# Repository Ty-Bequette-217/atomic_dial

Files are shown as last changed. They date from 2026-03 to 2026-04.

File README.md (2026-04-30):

# 🚧 GitHub still in progress 🚧
# The Atomic Dial
### by Yonathan Gur, Ryan Gelston, Ty Bequette, and Cody Fuh

---

## Overview
The Atomic Dial is an open-source, haptic-enabled smart knob powered by the RP2350B architecture. It provides software-defined mechanical feedback—such as detents, virtual end-stops, and magnetic resistance—using a brushless DC motor. An adaptation of the [SmartKnob](https://github.com/scottbez1/smartknob) project by Scott Bezek, this project adapts the original device to work smoothly with the RP2350B microcontroller. The board was designed to include header pins to plug in the [Proton development board](https://ece362-purdue.github.io/proton-labs/) designed by staff for ECE 36200: Microprocessor Systems and Interfacing at Purdue University.

## Board Design & Hardware Integration
Transitioning from the original ESP32-PICO architecture to the RP2350B required a redesign of the Base PCB and hardware routing to accommodate the Proton development board. We designed a custom baseplate PCB that features female headers specifically spaced to receive the Proton board. These header pins allow anyone with a Proton board to easily recreate this project and use it with their own boards. A bulk of the work done here was carefully rerouting the signals for each of the peripherals to match the correct function needed for compatibility with the proton board (see [electronics/ProjectPinAssignments.xlsx](https://github.com/Ty-Bequette-217/atomic_dial/blob/main/electronics/ProjectPinAssignments.xlsx)).

## Firmware Architecture
To make the RP2350B drive a display, read sensors, and commutate a motor simultaneously without stuttering, the firmware is divided into distinct, non-blocking layers built on the Raspberry Pi Pico C/C++ SDK.

### AS5600 Magnetic Encoder
The AS5600 serves as the primary feedback loop for our haptic system. Mounted directly below the diametric magnet on the motor shaft, it continuously reads the absolute angular position of the knob. By feeding this high-resolution rotational data back into the RP2350B, the firmware can calculate exact phase angles and trigger localized spikes in motor torque, allowing the user to feel physical "clicks" entirely generated by software.

### GC9A01 Round LCD
The primary user interface is driven by a 1.28-inch GC9A01 circular LCD, which receives data over the RP2350B's hardware SPI bus to maintain a high framerate.

#### Initialization for GC9A01
Bringing up the GC9A01 requires a precise sequence of initialization commands sent over SPI. The firmware configures the display out of sleep mode, sets the pixel format to 16-bit color (RGB565), defines the memory access control for correct screen orientation, and establishes the circular column and row address windows. A hardware reset line is toggled on boot to ensure the display controller starts in a known, clean state before accepting pixel data.

#### Inclusion of LVGL C Library
To handle the complex graphics, menus, and animations without writing pixel-level drawing routines from scratch, we integrated the [LVGL (Light and Versatile Graphics Library)](https://lvgl.io/). LVGL operates using internal draw buffers. We implemented a custom `disp_flush` callback function that takes LVGL's rendered buffer blocks and pushes them over the SPI bus to the GC9A01. This allows us to create smooth, professional-looking UI dials and scrolling menus that react in real-time to the motor encoder.

### TMC6300 Motor Driver
The physical haptic feedback is generated by a gimbal brushless DC motor driven by the TMC6300. The RP2350B uses its hardware PWM slices to output precisely timed, 3-phase sinusoidal waveforms (Space Vector PWM) to the motor coils. Because the PWM generation is handled by hardware timers rather than the main CPU loop, the motor commutation remains completely jitter-free even while the processor is busy rendering graphics or reading sensors.

### HX711 Load Cell Amplifier
To add a "push-to-click" dimension to the dial, we integrated SMD resistors acting as load cells monitored by an HX711 24-bit ADC. When the HX711 outout decreases below the threshold, a push is registered and changes the state of the device.

### LDR monitoring for LCD Brightness
To optimize visibility and power consumption, the dial features dynamic backlight adjustment. A Light Dependent Resistor (LDR) acts as an ambient light sensor, read continuously by the RP2350B's internal 12-bit ADC. The firmware maps these raw ADC values to a duty cycle percentage, which is then fed into a hardware PWM slice driving the `LCD_BACKLIGHT` pin. This ensures the display dims in dark rooms and ramps to full brightness in heavily lit environments without any manual user intervention.

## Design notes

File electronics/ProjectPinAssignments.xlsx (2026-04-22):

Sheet: Sheet1
 | Name | esp32 pin from sch | T-Micro32_Plus Pin Fcns | Configured in Code as | Corresponding rp2350 fcn | assign to pin
1 | TMC_DIAG | io36/svp | ADC0, GPIO36 |  | SIO (Digital In) (used for interrupt) | GPIO 14
2 | TMC_VL | io32 | Touch9, ADC4, GPIO32 |  | PWM 1A | GPIO 2
3 | TMC_WL | io33 | Touch8, ADC5, GPIO33 |  | PWM 2A | GPIO 4
4 | TMC_UL | io25 | DAC1, ADC2_8, GPIO25 |  | PWM 3A | GPIO 6
5 | TM_UH | io26 | DAC2, ADC2_9, GPIO26 |  | PWM 3B | GPIO 7
6 | TMC_VH | io27 | Touch7, ADC2_7, GPIO27 |  | PWM 1B | GPIO 3
7 | MAG_CSN | io14 | HSPI_CLK, Touch6, ADC2_6, GPIO14 |  | SPI1 CSn or SIO | GPIO 29
8 | TMC_WH | io12 | HSPI_Q, Touch5, ADC2_5, GPIO12 |  | PWM 2B | GPIO 5
9 | MAG_CLK | io13 |  |  | SPI1 SCK | GPIO 30
10 | MAG_DO | io37 |  |  | SPI1 RX | GPIO 28
11 | STRAIN_DO | io38 |  |  | HX711 Data (PIO / SIO Bitbanged) | GPIO 10
12 | LED_DATA_3V3 | io7 | ADC |  | SIO (LED has it's own async thing???) | GPIO 27
13 | SCL | io8 | ADC |  | I2C0 SCL | GPIO 13
14 | SDA | io15 |  |  | I2C0 SDA | GPIO 12
15 | STRAIN_SCK | io2 | HSPI_WP, Touch2, ADC2_2, GPIO2 |  | HX711 Clock (SIO Bitbanged) | GPIO 11
16 | LCD_RST | io4 | HSPI_HD, Touch0, ADC2_0, GPIO4 |  | Display Reset (SIO) | GPIO 20
17 | LCD_SCK | io20 | - |  | Display Clock SPI0 SCK | GPIO 18
18 | LCD_DATA | io5 | VSPI_SS |  | SPI0 TX | GPIO 19
19 | LCD_BACKLIGHT | io19 | VSPI_MISO |  | PWM 0A | GPIO 16
20 | LCD_CS | io21 | VSPI_HD, Wire_SDA |  | Chip Select(SPI0 CSn or SIO) | GPIO 17
21 | LCD_CMD | io22 | VSPI_WP, Wire_SCL |  | Data/Command (SIO) | GPIO 15
22 | DEBUG_TX |  |  |  | UART0 RX | GPIO 1
23 | DEBUG_RX |  |  |  | UART0 TX | GPIO 0
24 | USB_SERIAL_RXI | TXD |  |  | UART1 TX | GPIO 8
25 | USB_SERIAL_TXO | RXD |  |  | UART1 RX | GPIO 9

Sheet: RP 2350 Pins
GPIO | Usage | Target Fcn | F0 | F1 | F2 | F3 | F4 | F5 | F6 | F7 | F8 | F9 | F10 | F11 | F12
0 | DEBUG_RX | UART0 TX | SPI0 RX | UART0 TX | I2C0 SDA | PWM 0A | SIO | PIO0_0 | PIO1_0 | PIO2_0 | USB OVR | GPCK0 | - | - | PROC0
1 | DEBUG_TX | UART0 RX | SPI0 CSn | UART0 RX | I2C0 SCL | PWM 0B | SIO | PIO0_1 | PIO1_1 | PIO2_1 | USB VBUS | GPCK1 | - | - | PROC0
2 | TMC_VL | PWM 1A | SPI0 SCK | UART0 CTS | I2C1 SDA | PWM 1A | SIO | PIO0_2 | PIO1_2 | PIO2_2 | USB OVR | - | - | - | PROC0
3 | TMC_VH | PWM 1B | SPI0 TX | UART0 RTS | I2C1 SCL | PWM 1B | SIO | PIO0_3 | PIO1_3 | PIO2_3 | USB VBUS | - | - | - | PROC0
4 | TMC_WL | PWM 2A | SPI0 RX | UART1 TX | I2C0 SDA | PWM 2A | SIO | PIO0_4 | PIO1_4 | PIO2_4 | USB OVR | GPCK2 | - | - | PROC0
5 | TMC_WH | PWM 2B | SPI0 CSn | UART1 RX | I2C0 SCL | PWM 2B | SIO | PIO0_5 | PIO1_5 | PIO2_5 | USB VBUS | GPCK3 | - | - | PROC0
6 | TMC_UL | PWM 3A | SPI0 SCK | UART1 CTS | I2C1 SDA | PWM 3A | SIO | PIO0_6 | PIO1_6 | PIO2_6 | USB OVR | - | - | - | PROC0
7 | TMC_UH | PWM 3B | SPI0 TX | UART1 RTS | I2C1 SCL | PWM 3B | SIO | PIO0_7 | PIO1_7 | PIO2_7 | USB VBUS | - | - | - | PROC0
8 | USB_SERIAL_RXI | UART1 TX | SPI1 RX | UART1 TX | I2C0 SDA | PWM 4A | SIO | PIO0_8 | PIO1_8 | PIO2_8 | USB OVR | GPCK0 | - | - | PROC1
9 | USB_SERIAL_TXO | UART1 RX | SPI1 CSn | UART1 RX | I2C0 SCL | PWM 4B | SIO | PIO0_9 | PIO1_9 | PIO2_9 | USB VBUS | GPCK1 | - | - | PROC1
10 | STRAIN_DO | SIO | SPI1 SCK | UART1 CTS | I2C1 SDA | PWM 5A | SIO | PIO0_10 | PIO1_10 | PIO2_10 | USB OVR | - | - | - | PROC1
11 | STRAIN_SCK | SIO | SPI1 TX | UART1 RTS | I2C1 SCL | PWM 5B | SIO | PIO0_11 | PIO1_11 | PIO2_11 | USB VBUS | - | - | - | PROC1
12 | SDA | I2C0 SDA | SPI1 RX | UART0 TX | I2C0 SDA | PWM 6A | SIO | PIO0_12 | PIO1_12 | PIO2_12 | USB OVR | GPCK2 | - | - | PROC1
13 | SCL | I2C0 SCL | SPI1 CSn | UART0 RX | I2C0 SCL | PWM 6B | SIO | PIO0_13 | PIO1_13 | PIO2_13 | USB VBUS | GPCK3 | - | - | PROC1
14 | TMC_DIAG | SIO | SPI1 SCK | UART0 CTS | I2C1 SDA | PWM 7A | SIO | PIO0_14 | PIO1_14 | PIO2_14 | USB OVR | - | - | - | PROC1
15 | LCD_CMD | SIO | SPI1 TX | UART0 RTS | I2C1 SCL | PWM 7B | SIO | PIO0_15 | PIO1_15 | PIO2_15 | USB VBUS | - | - | - | PROC1
16 | LCD_BACKLIGHT | PWM 0A | SPI0 RX | UART0 TX | I2C0 SDA | PWM 0A | SIO | PIO0_16 | PIO1_16 | PIO2_16 | USB OVR | GPCK0 | - | - | PROC0
17 | LCD_CS | SIO/SPI0 CSn | SPI0 CSn | UART0 RX | I2C0 SCL | PWM 0B | SIO | PIO0_17 | PIO1_17 | PIO2_17 | USB VBUS | GPCK1 | - | - | PROC0
18 | LCD_SCK | SPI0 SCK | SPI0 SCK | UART0 CTS | I2C1 SDA | PWM 1A | SIO | PIO0_18 | PIO1_18 | PIO2_18 | USB OVR | - | - | - | PROC0
19 | LCD_DATA | SPI0 TX | SPI0 TX | UART0 RTS | I2C1 SCL | PWM 1B | SIO | PIO0_19 | PIO1_19 | PIO2_19 | USB VBUS | - | - | - | PROC0
20 | LCD_RST | SIO | SPI0 RX | UART1 TX | I2C0 SDA | PWM 2A | SIO | PIO0_20 | PIO1_20 | PIO2_20 | USB OVR | GPCK2 | - | - | PROC0
21 | Proton Button |  | SPI0 CSn | UART1 RX | I2C0 SCL | PWM 2B | SIO | PIO0_21 | PIO1_21 | PIO2_21 | USB VBUS | GPCK3 | - | - | PROC0
22 | Proton LED |  | SPI0 SCK | UART1 CTS | I2C1 SDA | PWM 3A | SIO | PIO0_22 | PIO1_22 | PIO2_22 | USB OVR | - | - | - | PROC0
23 | Proton LED |  | SPI0 TX | UART1 RTS | I2C1 SCL | PWM 3B | SIO | PIO0_23 | PIO1_23 | PIO2_23 | USB VBUS | - | - | - | PROC0
24 | Proton LED |  | SPI1 RX | UART1 TX | I2C0 SDA | PWM 4A | SIO | PIO0_24 | PIO1_24 | PIO2_24 | USB OVR | GPCK0 | - | - | PROC1
25 | Proton LED |  | SPI1 CSn | UART1 RX | I2C0 SCL | PWM 4B | SIO | PIO0_25 | PIO1_25 | PIO2_25 | USB VBUS | GPCK1 | - | - | PROC1
26 | Proton Button |  | SPI1 SCK | UART1 CTS | I2C1 SDA | PWM 5A | SIO | PIO0_26 | PIO1_26 | PIO2_26 | USB OVR | - | - | - | PROC1
27 | LED_DATA_3V3 | SIO | SPI1 TX | UART1 RTS | I2C1 SCL | PWM 5B | SIO | PIO0_27 | PIO1_27 | PIO2_27 | USB VBUS | - | - | - | PROC1
28 | MAG_DO | SPI1 RX | SPI1 RX | UART0 TX | I2C0 SDA | PWM 6A | SIO | PIO0_28 | PIO1_28 | PIO2_28 | USB OVR | GPCK2 | - | HSTX | PROC1
29 | MAG_CSN | CSn/SIO | SPI1 CSn | UART0 RX | I2C0 SCL | PWM 6B | SIO | PIO0_29 | PIO1_29 | PIO2_29 | USB VBUS | GPCK3 | - | HSTX | PROC1
30 | MAG_CLK | SPI1 SCK | SPI1 SCK | UART0 CTS | I2C1 SDA | PWM 7A | SIO | PIO0_30 | PIO1_30 | PIO2_30 | USB OVR | - | - | HSTX | PROC1
31 | (Avail) | - | SPI1 TX | UART0 RTS | I2C1 SCL | PWM 7B | SIO | PIO0_31 | PIO1_31 | PIO2_31 | USB VBUS | - | - | HSTX | PROC1
32 | (Avail) | - | SPI0 RX | UART0 TX | I2C0 SDA | PWM 8A | SIO | PIO0_0 | PIO1_0 | PIO2_0 | USB OVR | GPCK0 | - | HSTX | PROC0
33 | (Avail) | - | SPI0 CSn | UART0 RX | I2C0 SCL | PWM 8B | SIO | PIO0_1 | PIO1_1 | PIO2_1 | USB VBUS | GPCK1 | - | HSTX | PROC0
34 | (Avail) | - | SPI0 SCK | UART0 CTS | I2C1 SDA | PWM 9A | SIO | PIO0_2 | PIO1_2 | PIO2_2 | USB OVR | - | - | HSTX | PROC0
35 | (Avail) | - | SPI0 TX | UART0 RTS | I2C1 SCL | PWM 9B | SIO | PIO0_3 | PIO1_3 | PIO2_3 | USB VBUS | - | - | HSTX | PROC0
36 | (Avail) | - | SPI0 RX | UART1 TX | I2C0 SDA | PWM 10A | SIO | PIO0_4 | PIO1_4 | PIO2_4 | USB OVR | GPCK2 | - | HSTX | PROC0
37 | (Avail) | - | SPI0 CSn | UART1 RX | I2C0 SCL | PWM 10B | SIO | PIO0_5 | PIO1_5 | PIO2_5 | USB VBUS | GPCK3 | - | HSTX | PROC0
38 | (Avail) | - | SPI0 SCK | UART1 CTS | I2C1 SDA | PWM 11A | SIO | PIO0_6 | PIO1_6 | PIO2_6 | USB OVR | - | - | HSTX | PROC0
39 | (Avail) | - | SPI0 TX | UART1 RTS | I2C1 SCL | PWM 11B | SIO | PIO0_7 | PIO1_7 | PIO2_7 | USB VBUS | - | - | HSTX | PROC0
40 | LDR | ADC 5 | SPI1 RX | UART1 TX | I2C0 SDA | PWM 8A | SIO | PIO0_8 | PIO1_8 | PIO2_8 | USB OVR | GPCK0 | ADC 0 | HSTX | PROC1
41 | TMC_VIO | SIO | SPI1 CSn | UART1 RX | I2C0 SCL | PWM 8B | SIO | PIO0_9 | PIO1_9 | PIO2_9 | USB VBUS | GPCK1 | ADC 1 | HSTX | PROC1
42 | (Avail) | - | SPI1 SCK | UART1 CTS | I2C1 SDA | PWM 9A | SIO | PIO0_10 | PIO1_10 | PIO2_10 | USB OVR | - | ADC 2 | HSTX | PROC1
43 | (Avail) | - | SPI1 TX | UART1 RTS | I2C1 SCL | PWM 9B | SIO | PIO0_11 | PIO1_11 | PIO2_11 | USB VBUS | - | ADC 3 | HSTX | PROC1
44 | (Avail) | - | SPI1 RX | UART0 TX | I2C0 SDA | PWM 10A | SIO | PIO0_12 | PIO1_12 | PIO2_12 | USB OVR | GPCK2 | ADC 4 | HSTX | PROC1
45 | (Avail) | - | SPI1 CSn | UART0 RX | I2C0 SCL | PWM 10B | SIO | PIO0_13 | PIO1_13 | PIO2_13 | USB VBUS | GPCK3 | ADC 5 | HSTX | PROC1
46 | (Avail) | - | SPI1 SCK | UART0 CTS | I2C1 SDA | PWM 11A | SIO | PIO0_14 | PIO1_14 | PIO2_14 | USB OVR | - | ADC 6 | HSTX | PROC1
47 | (Avail) | - | SPI1 TX | UART0 RTS | I2C1 SCL | PWM 11B | SIO | PIO0_15 | PIO1_15 | PIO2_15 | USB VBUS | - | ADC 7 | HSTX | PROC1

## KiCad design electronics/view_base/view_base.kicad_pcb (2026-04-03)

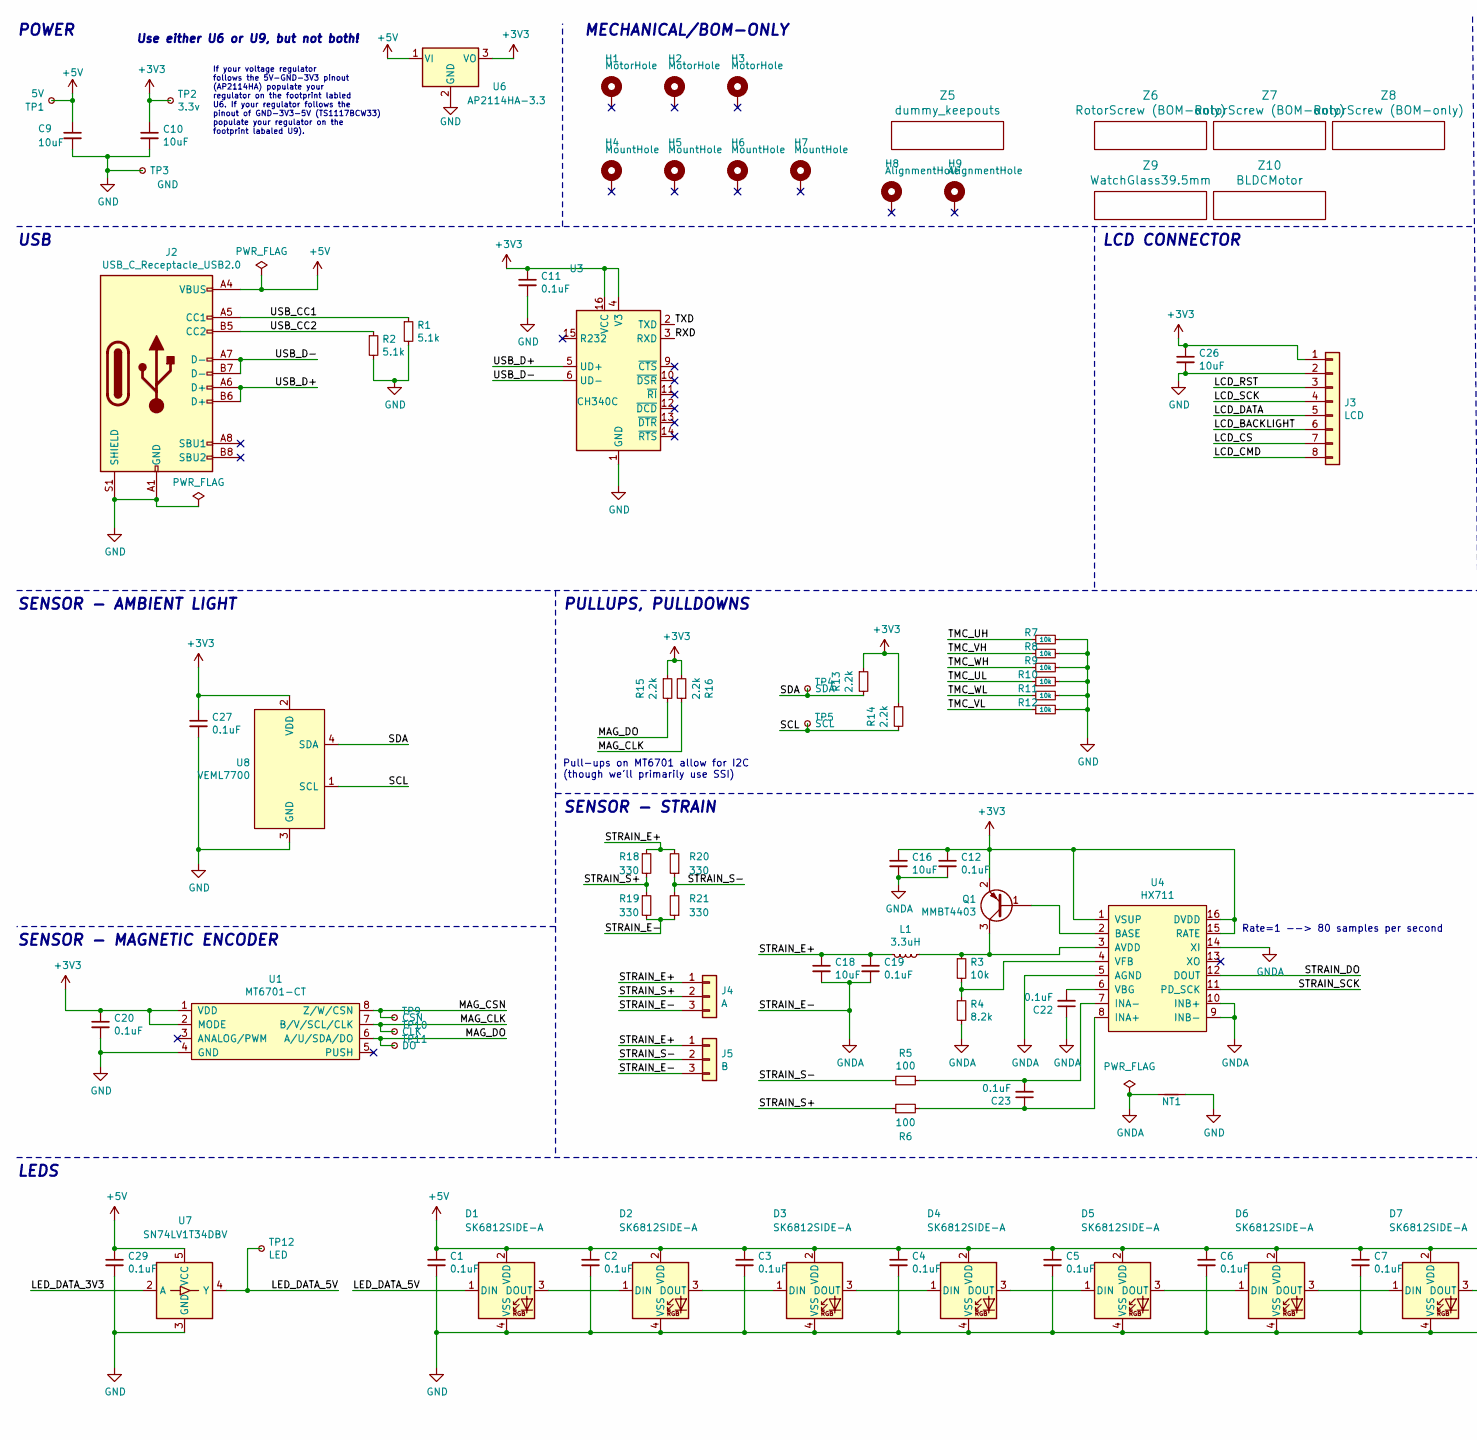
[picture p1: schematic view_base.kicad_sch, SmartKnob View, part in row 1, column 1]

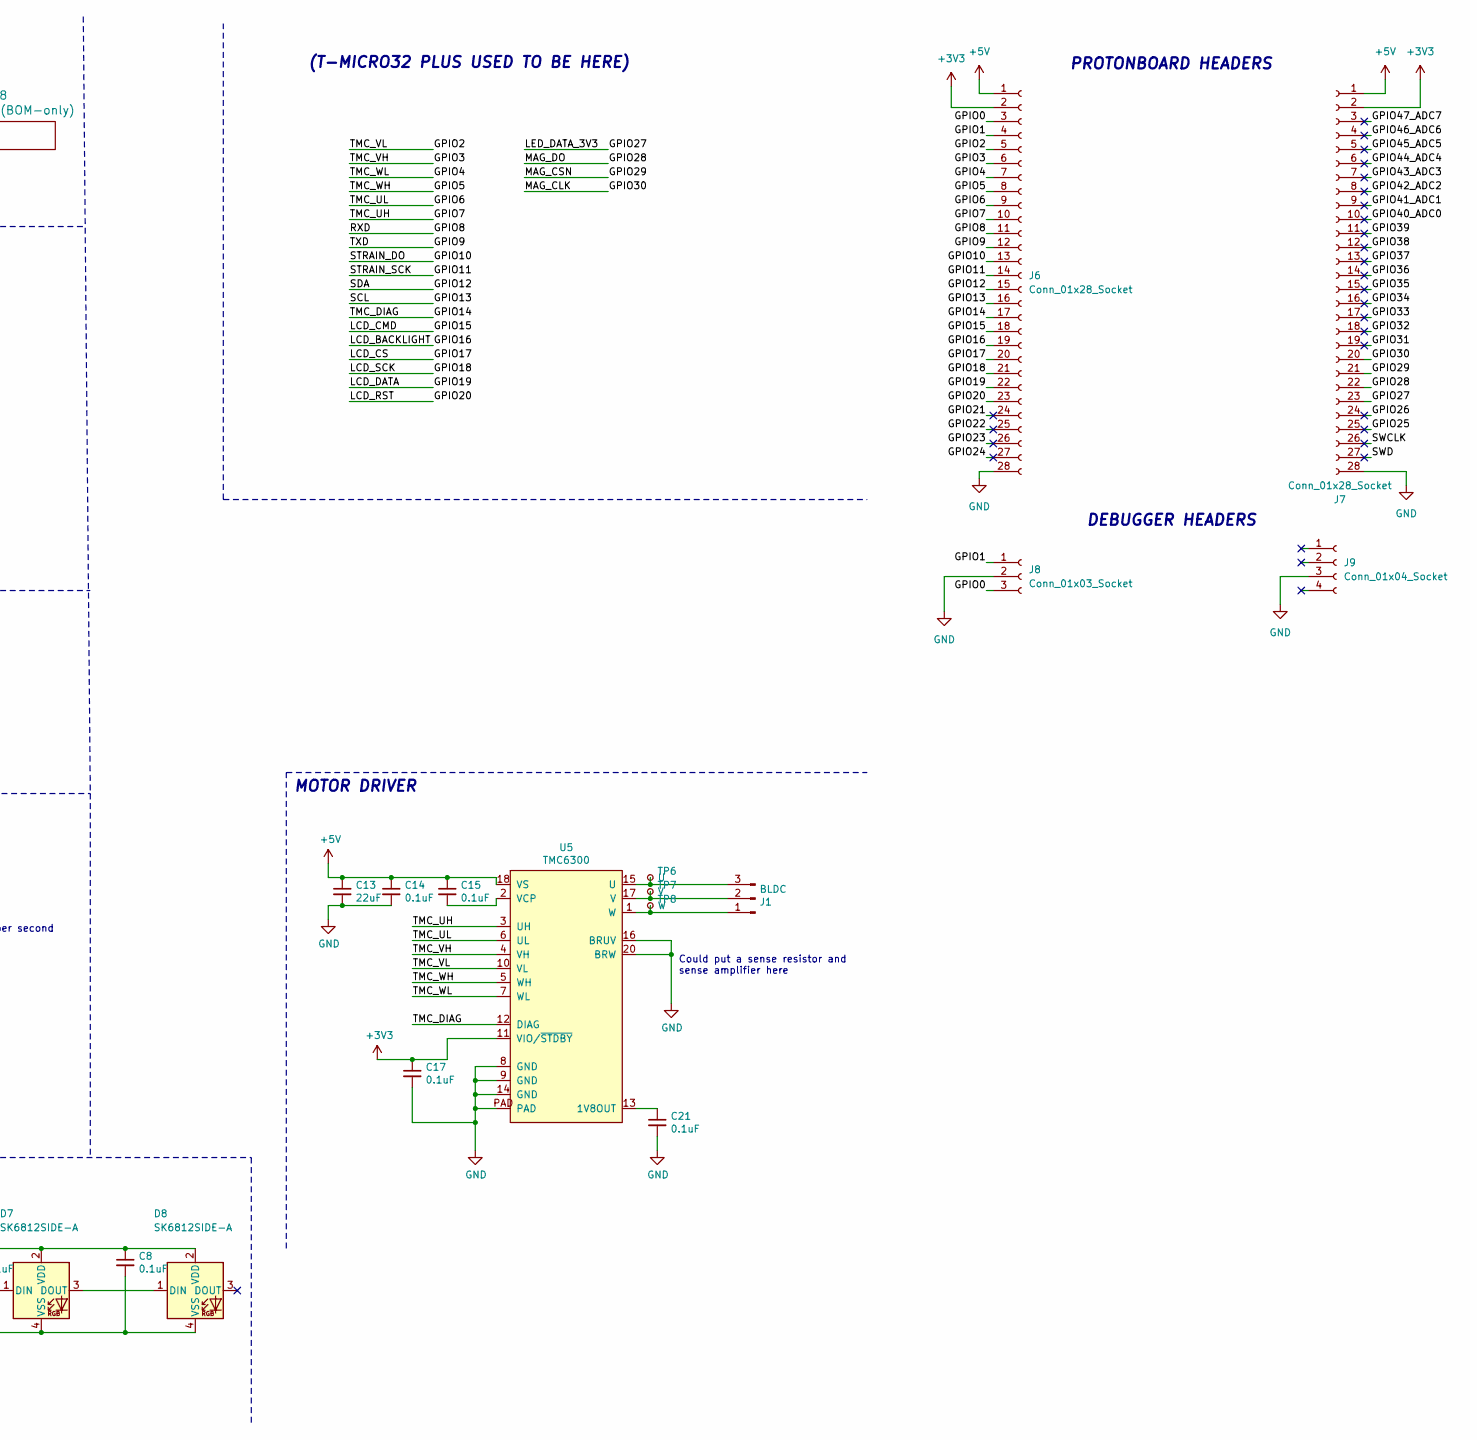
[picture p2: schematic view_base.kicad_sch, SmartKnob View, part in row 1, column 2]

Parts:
C1, C2, C3, C4, C5, C6, C7, C8, C11, C12, C14, C15, C17, C19, C20, C21, C22, C23, C27, C29: 0.1uF; C_0603_1608Metric; LCSC C1591
C9, C10, C16, C18, C26: 10uF; C_0805_2012Metric; LCSC C2922480
C13: 22uF; C_0805_2012Metric; LCSC C98190
D1, D2, D3, D4, D5, D6, D7, D8: SK6812SIDE-A; SK6812-SIDE-A; Digikey 1528-4691-ND
H1, H2, H3: MotorHole; MountingHole_M1.6; LCSC C2931389
H4, H5, H6, H7: MountHole; MountingHole_2.2mm_M2_ISO7380_Pad_NonVirtual; LCSC C2911210 or C2911532 (screw), C2961595 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
H8, H9: AlignmentHole; MountingHole_2.2mm_M2_ISO7380_Pad_NonVirtual
J1: BLDC; 532610371; LCSC C293630
J2: USB_C_Receptacle_USB2.0; USB4510_NoPaste; LCSC C428463
J3: LCD; SolderPads_2mm_8
J4: A; SolderPads_2mm_3_STRAIN
J5: B; SolderPads_2mm_3_STRAIN
J6, J7: Conn_01x28_Socket; PinSocket_1x28_P2.54mm_Vertical
J8: Conn_01x03_Socket; PinSocket_1x03_P2.54mm_Vertical
J9: Conn_01x04_Socket; PinSocket_1x04_P2.54mm_Vertical
L1: 3.3uH; L_0805_2012Metric; LCSC C307744
NT1: NetTie_2; NetTie-2_SMD_Pad0.5mm
Q1: MMBT4403; SOT-23; LCSC C78864
R1, R2: 5.1k; R_0603_1608Metric; LCSC C105580
R3, R7, R8, R9, R10, R11, R12: 10k; R_0603_1608Metric; LCSC C98220
R4: 8.2k; R_0603_1608Metric; LCSC C114637
R5, R6: 100; R_0603_1608Metric; LCSC C319953
R13, R14, R15, R16: 2.2k; R_0603_1608Metric; LCSC C4190
R18, R19, R20, R21: 330; R_2512_6332Metric; LCSC C19866
TP1: 5V; TestPoint_Pad_D2.0mm_ValueSilk
TP2: 3.3v; TestPoint_Pad_D2.0mm_ValueSilk
TP3: GND; TestPoint_Pad_D2.0mm_ValueSilk
TP4: SDA; TestPoint_Pad_D2.0mm_ValueSilk
TP5: SCL; TestPoint_Pad_D2.0mm_ValueSilk
TP6: U; TestPoint_Pad_D2.0mm_ValueSilk
TP7: V; TestPoint_Pad_D2.0mm_ValueSilk
TP8: W; TestPoint_Pad_D2.0mm_ValueSilk
TP9: CSN; TestPoint_Pad_D2.0mm_ValueSilk
TP10: CLK; TestPoint_Pad_D2.0mm_ValueSilk
TP11: DO; TestPoint_Pad_D2.0mm_ValueSilk
TP12: LED; TestPoint_Pad_D2.0mm_ValueSilk
U1: MT6701-CT; SOIC-8_3.9x4.9mm_P1.27mm; LCSC C2856764, or C3003196
U3: CH340C; SOIC-16_3.9x9.9mm_P1.27mm; LCSC C84681
U4: HX711; SOIC-16_3.9x9.9mm_P1.27mm; LCSC C43656
U5: TMC6300; QFN-20-1EP_3x3mm_P0.4mm_EP1.65x1.65mm_ThermalVias_LargerVia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; Digikey TMC6300-LA-T
U6: AP2114HA-3.3; SOT-223-3_TabPin2_InGndOut; LCSC C460314
U7: SN74LV1T34DBV; SOT-23-5; LCSC C100024
U8: VEML7700; VEML7700-TOP; Digikey VEML7700-TT
Z5: dummy_keepouts; ViewKeepouts3d
Z6, Z7, Z8: RotorScrew (BOM-only); bom_only_no_pin
Z9: WatchGlass39.5mm; bom_only_no_pin
Z10: BLDCMotor; bom_only_no_pin

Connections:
+3V3: C10.1, C11.1, C12.1, C16.1, C17.1, C20.1, C26.1, C27.1, J3.1, J6.2, J7.2, Q1.2 (E), R13.1, R14.1, R15.1, R16.2, TP2.1, U1.1 (VDD), U1.2 (MODE), U3.4 (V3), U3.16 (VCC), U4.1 (VSUP), U4.15 (RATE), U4.16 (DVDD), U5.11 (VIO/~STDBY), U6.3 (VO), U8.2 (VDD); also elsewhere on the board
+5V: C1.1, C2.1, C3.1, C4.1, C5.1, C6.1, C7.1, C8.1, C9.1, C13.1, C14.1, C15.1, C29.1, D1.2 (VDD), D2.2 (VDD), D3.2 (VDD), D4.2 (VDD), D5.2 (VDD), D6.2 (VDD), D7.2 (VDD), D8.2 (VDD), J2.A4 (VBUS), J2.A9 (VBUS), J2.B4 (VBUS), J2.B9 (VBUS), J6.1, J7.1, TP1.1, U5.18 (VS), U6.1 (VI), U7.5 (VCC); also elsewhere on the board
/GPIO0: J6.3, J8.3
/GPIO1: J6.4, J8.1
/GPIO2: J6.5, R12.1, U5.10 (VL)
/GPIO3: J6.6, R8.1, U5.4 (VH)
/GPIO4: J6.7, R11.1, U5.7 (WL)
/GPIO5: J6.8, R9.1, U5.5 (WH)
/GPIO6: J6.9, R10.1, U5.6 (UL)
/GPIO7: J6.10, R7.1, U5.3 (UH)
/GPIO8: J6.11, U3.3 (RXD)
/GPIO9: J6.12, U3.2 (TXD)
/GPIO10: J6.13, U4.12 (DOUT)
/GPIO11: J6.14, U4.11 (PD_SCK)
/GPIO12: J6.15, R13.2, TP4.1, U8.4 (SDA)
/GPIO13: J6.16, R14.2, TP5.1, U8.1 (SCL)
/GPIO14: J6.17, U5.12 (DIAG)
/GPIO15: J3.8, J6.18
/GPIO16: J3.6, J6.19
/GPIO17: J3.7, J6.20
/GPIO18: J3.4, J6.21
/GPIO19: J3.5, J6.22
/GPIO20: J3.3, J6.23
/GPIO21: J6.24
/GPIO22: J6.25
/GPIO23: J6.26
/GPIO24: J6.27
/GPIO25: J7.25
/GPIO26: J7.24
/GPIO27: J7.23, U7.2 (A)
/GPIO28: J7.22, R15.2, TP11.1, U1.6 (A/U/SDA/DO)
/GPIO29: J7.21, TP9.1, U1.8 (Z/W/CSN)
/GPIO30: J7.20, R16.1, TP10.1, U1.7 (B/V/SCL/CLK)
/GPIO31: J7.19
/GPIO32: J7.18
/GPIO33: J7.17
/GPIO34: J7.16
/GPIO35: J7.15
/GPIO36: J7.14
/GPIO37: J7.13
/GPIO38: J7.12
/GPIO39: J7.11
/GPIO40_ADC0: J7.10
/GPIO41_ADC1: J7.9
/GPIO42_ADC2: J7.8
/GPIO43_ADC3: J7.7
/GPIO44_ADC4: J7.6
/GPIO45_ADC5: J7.5
/GPIO46_ADC6: J7.4
/GPIO47_ADC7: J7.3
/LED_DATA_5V: D1.1 (DIN), TP12.1, U7.4 (Y)
/STRAIN_E+: C18.1, C19.1, J4.1, J5.1, L1.2, R18.1, R20.2
/STRAIN_S+: J4.2, R6.1, R18.2, R19.1
/STRAIN_S-: J5.2, R5.2, R20.1, R21.2
/SWCLK: J7.26
/SWD: J7.27
/USB_CC1: J2.A5 (CC1), R1.1
/USB_CC2: J2.B5 (CC2), R2.1
/USB_D+: J2.A6 (D+), J2.B6 (D+), U3.5 (UD+)
/USB_D-: J2.A7 (D-), J2.B7 (D-), U3.6 (UD-)
GND: C1.2, C2.2, C3.2, C4.2, C5.2, C6.2, C7.2, C8.2, C9.2, C10.2, C11.2, C13.2, C14.2, C17.2, C20.2, C21.2, C26.2, C27.2, C29.2, D1.4 (VSS), D2.4 (VSS), D3.4 (VSS), D4.4 (VSS), D5.4 (VSS), D6.4 (VSS), D7.4 (VSS), D8.4 (VSS), J2.A1 (GND), J2.A12 (GND), J2.B1 (GND), J2.B12 (GND), J2.S1 (SHIELD), J3.2, J6.28, J7.28, J8.2, J9.3, NT1.2, R1.2, R2.2, R7.2, R8.2, R9.2, R10.2, R11.2, R12.2, TP3.1, U1.4 (GND), U3.1 (GND), U5.8 (GND), U5.9 (GND), U5.14 (GND), U5.16 (BRUV), U5.20 (BRW), U5.PAD, U6.2 (GND), U7.3 (GND), U8.3 (GND); also elsewhere on the board
GNDA: C12.2, C16.2, C18.2, C19.2, C22.1, J4.3, J5.3, NT1.1, R4.2, R19.2, R21.1, U4.5 (AGND), U4.9 (INB-), U4.10 (INB+), U4.14 (XI)
unnamed: D1.3 (DOUT), D2.1 (DIN)
unnamed: D2.3 (DOUT), D3.1 (DIN)
unnamed: D3.3 (DOUT), D4.1 (DIN)
unnamed: D4.3 (DOUT), D5.1 (DIN)
unnamed: D5.3 (DOUT), D6.1 (DIN)
unnamed: D6.3 (DOUT), D7.1 (DIN)
unnamed: D7.3 (DOUT), D8.1 (DIN)
unnamed: J1.1, TP8.1, U5.1 (W)
unnamed: J1.2, TP7.1, U5.17 (V)
unnamed: J1.3, TP6.1, U5.15 (U)
unnamed: Q1.1 (B), U4.2 (BASE)
unnamed: L1.1, Q1.3 (C), R3.1, U4.3 (AVDD)
unnamed: C23.1, R6.2, U4.8 (INA+)
unnamed: C23.2, R5.1, U4.7 (INA-)
unnamed: C22.2, U4.6 (VBG)
unnamed: R3.2, R4.1, U4.4 (VFB)
unnamed: C21.1, U5.13 (1V8OUT)
unnamed: C15.2, U5.2 (VCP)

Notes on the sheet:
POWER
Could put a sense resistor and sense amplifier here
PROTONBOARD HEADERS
(T-MICRO32 PLUS USED TO BE HERE)
If your voltage regulator follows the 5V-GND-3V3 pinout (AP2114HA) populate your regulator on the footprint labled U6. If your regulator follows the pinout of GND-3V3-5V (TS1117BCW33) populate your regulator on the footprint labaled U9).
SENSOR - MAGNETIC ENCODER
MOTOR DRIVER
MECHANICAL/BOM-ONLY
Pull-ups on MT6701 allow for I2C (though we'll primarily use SSI)
Use either U6 or U9, but not both!
Rate=1 --> 80 samples per second
SENSOR - AMBIENT LIGHT
USB
DEBUGGER HEADERS
SENSOR - STRAIN
LEDS
PULLUPS, PULLDOWNS
LCD CONNECTOR

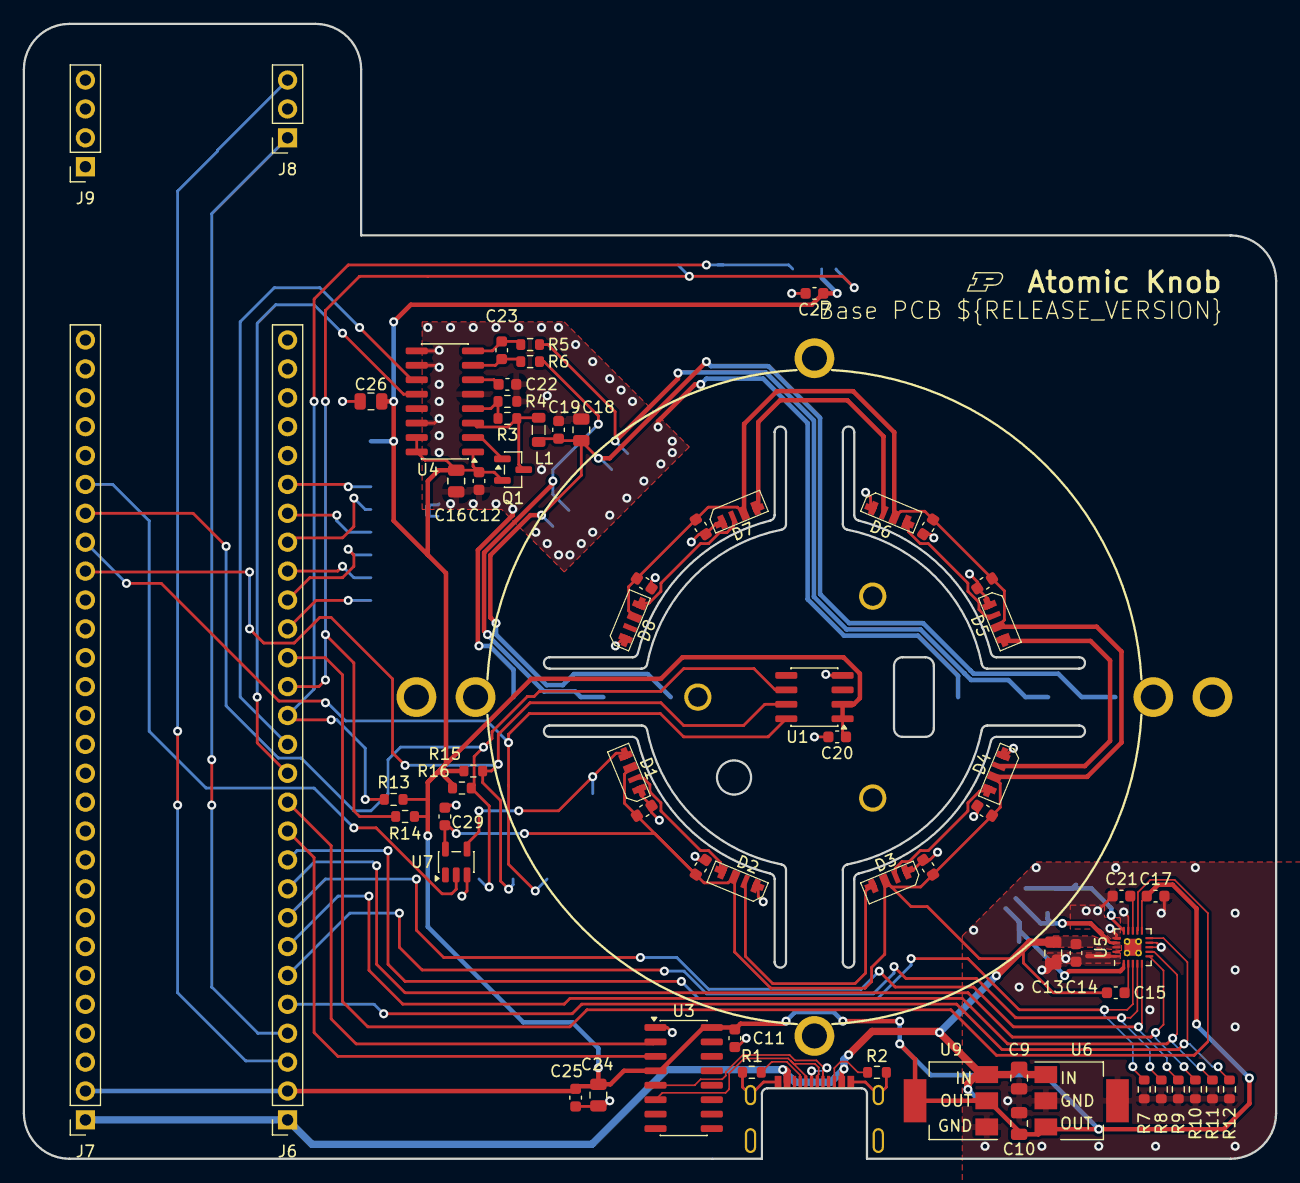
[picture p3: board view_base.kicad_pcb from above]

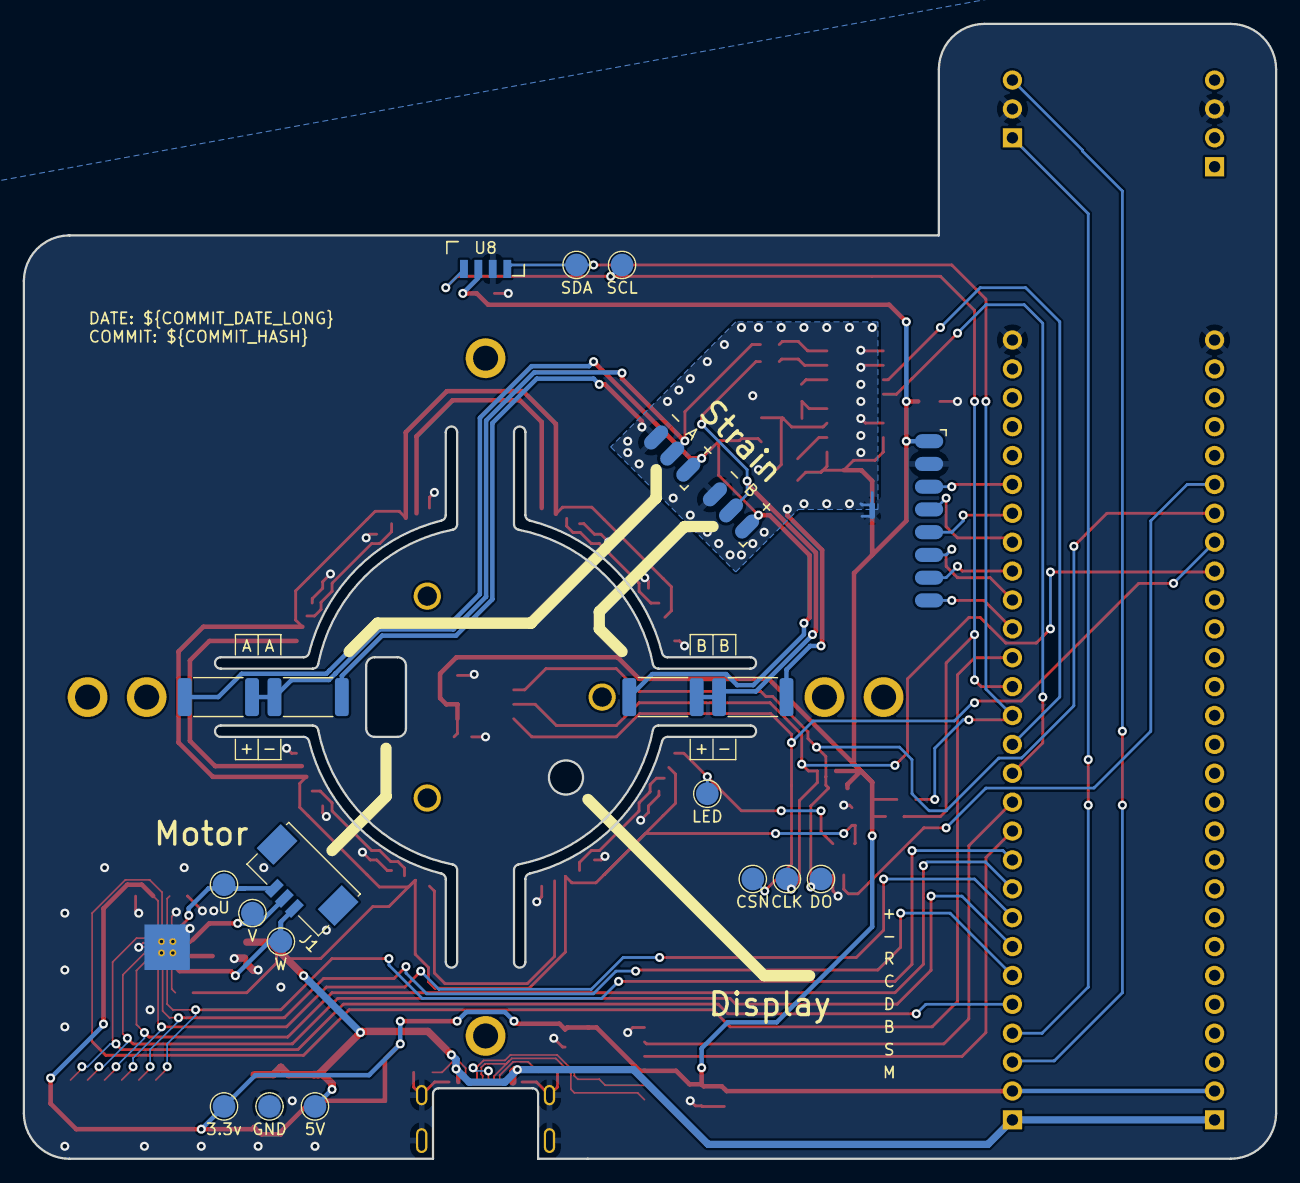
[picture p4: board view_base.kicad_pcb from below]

Board: 2 copper layers, 110.1 x 99.8 mm, 103 parts (22 on the bottom side), 55 nets.

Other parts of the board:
C24: 10uF; C_0805_2012Metric
C25: 0.1uF; C_0603_1608Metric
U9: TS1117BCW33_RPG; SOT-223-3_TabPin2_GndOutIn

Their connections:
+3V3: C24.1, C25.1, U9.2 (Output); also elsewhere on the board
+5V: U9.3 (Input); also elsewhere on the board
GND: C24.2, C25.2, U9.1 (GND); also elsewhere on the board

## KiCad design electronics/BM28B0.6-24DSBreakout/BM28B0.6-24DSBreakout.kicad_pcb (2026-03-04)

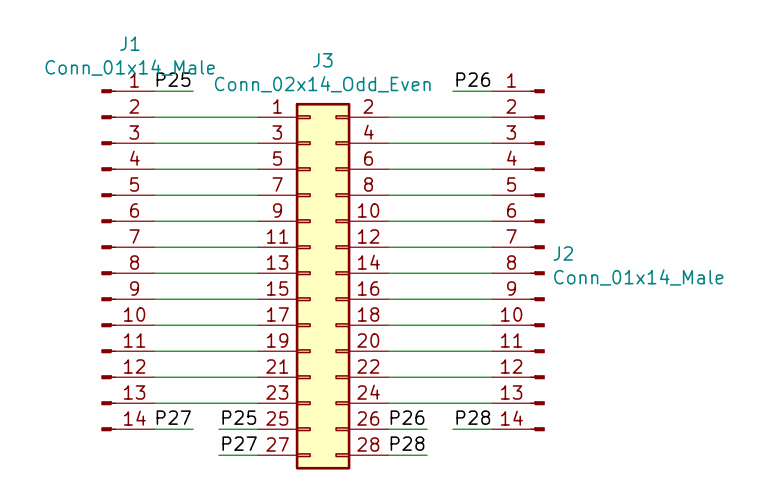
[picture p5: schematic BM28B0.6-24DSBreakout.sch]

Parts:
J1, J2: Conn_01x14_Male; PinHeader_1x14_P2.54mm_Vertical
J3: Conn_02x14_Odd_Even; BM28B0.6-24DS

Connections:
/P25: J1.1, J3.25
/P26: J2.1, J3.26
/P27: J1.14, J3.27
/P28: J2.14, J3.28
unnamed: J1.2, J3.1
unnamed: J1.3, J3.3
unnamed: J1.4, J3.5
unnamed: J1.5, J3.7
unnamed: J1.6, J3.9
unnamed: J1.7, J3.11
unnamed: J1.8, J3.13
unnamed: J1.9, J3.15
unnamed: J1.10, J3.17
unnamed: J1.11, J3.19
unnamed: J1.12, J3.21
unnamed: J1.13, J3.23
unnamed: J2.2, J3.2
unnamed: J2.3, J3.4
unnamed: J2.4, J3.6
unnamed: J2.5, J3.8
unnamed: J2.6, J3.10
unnamed: J2.7, J3.12
unnamed: J2.8, J3.14
unnamed: J2.9, J3.16
unnamed: J2.10, J3.18
unnamed: J2.11, J3.20
unnamed: J2.12, J3.22
unnamed: J2.13, J3.24

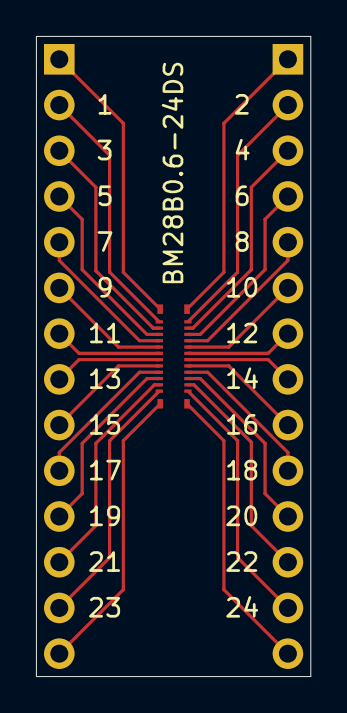
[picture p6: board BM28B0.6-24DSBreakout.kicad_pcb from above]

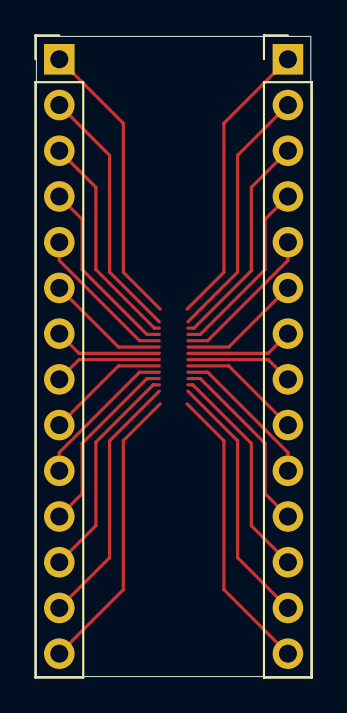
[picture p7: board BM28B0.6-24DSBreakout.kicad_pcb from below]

Board: 2 copper layers, 15.2 x 35.6 mm, 3 parts (2 on the bottom side), 28 nets.

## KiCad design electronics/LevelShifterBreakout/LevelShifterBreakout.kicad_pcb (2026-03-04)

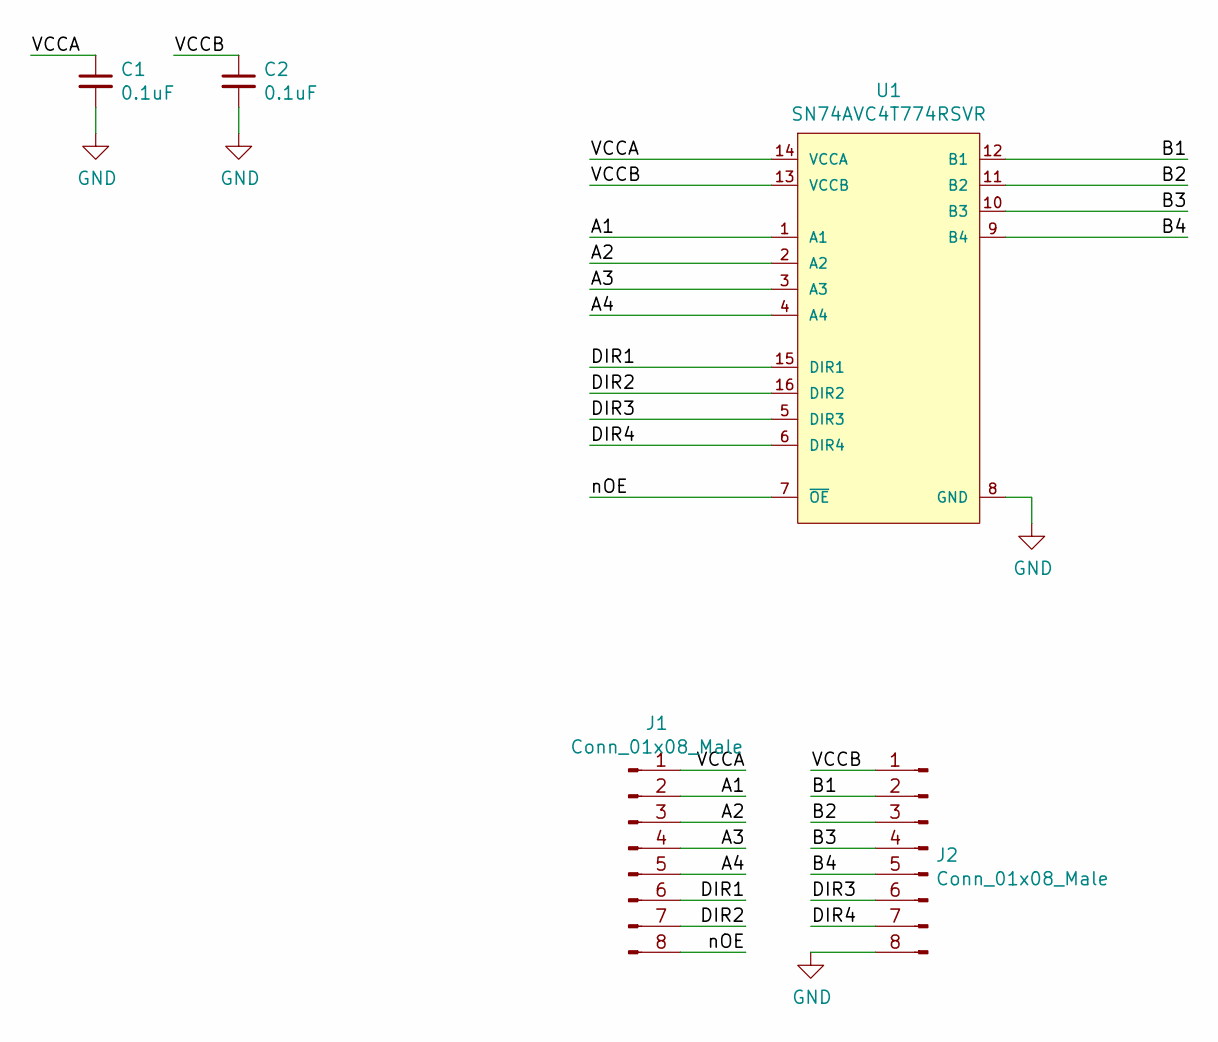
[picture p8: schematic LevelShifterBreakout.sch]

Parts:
C1, C2: 0.1uF; C_0805_2012Metric_Pad1.18x1.45mm_HandSolder
J1, J2: Conn_01x08_Male; PinHeader_1x08_P2.54mm_Vertical
U1: SN74AVC4T774RSVR; Texas_Instruments-RSV_R-PUQFN-N16-0-0-0; Voltage - VCCA 1.2V ~ 3.6V; Voltage - VCCB 1.2V ~ 3.6V; mouser part number 595-SN74AVC4T774RSVR; digikey description Voltage Level Translator Bidirectional 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

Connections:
/A1: J1.2, U1.1 (A1)
/A2: J1.3, U1.2 (A2)
/A3: J1.4, U1.3 (A3)
/A4: J1.5, U1.4 (A4)
/B1: J2.2, U1.12 (B1)
/B2: J2.3, U1.11 (B2)
/B3: J2.4, U1.10 (B3)
/B4: J2.5, U1.9 (B4)
/DIR1: J1.6, U1.15 (DIR1)
/DIR2: J1.7, U1.16 (DIR2)
/DIR3: J2.6, U1.5 (DIR3)
/DIR4: J2.7, U1.6 (DIR4)
/VCCA: C1.1, J1.1, U1.14 (VCCA)
/VCCB: C2.1, J2.1, U1.13 (VCCB)
/nOE: J1.8, U1.7 (~OE~)
GND: C1.2, C2.2, J2.8, U1.8 (GND)

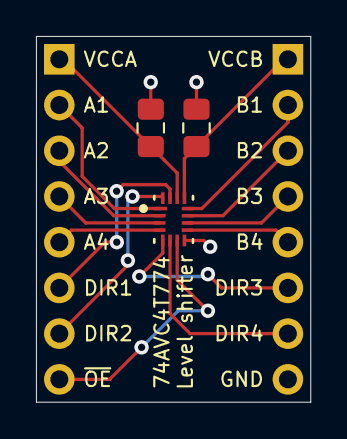
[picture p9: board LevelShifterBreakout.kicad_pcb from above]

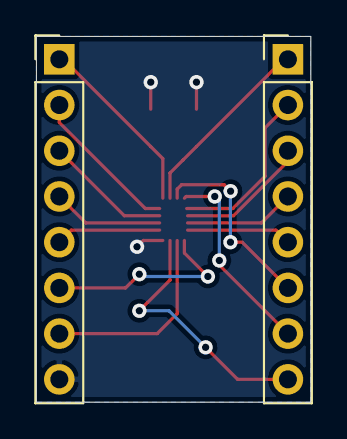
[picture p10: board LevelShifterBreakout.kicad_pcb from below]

Board: 2 copper layers, 15.2 x 20.3 mm, 5 parts (2 on the bottom side), 16 nets.

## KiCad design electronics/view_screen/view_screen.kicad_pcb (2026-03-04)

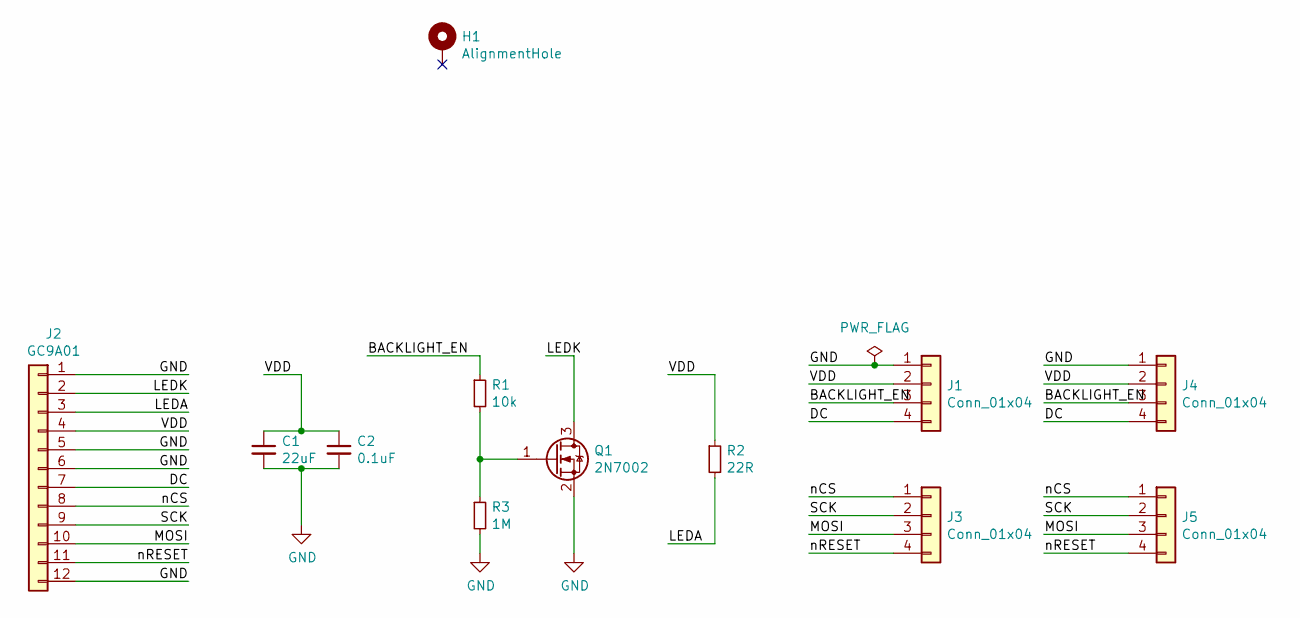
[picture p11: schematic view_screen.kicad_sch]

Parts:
C1: 22uF; C_0805_2012Metric; Digikey 1276-CL21A226MAYNNNECT-ND
C2: 0.1uF; C_0603_1608Metric; Digikey 1276-1935-1-ND
H1: AlignmentHole; AlignmentHole_1.6
J1, J3, J4, J5: Conn_01x04; SolderPads_2mm_4
J2: GC9A01; GC9A01Round1.28; Digikey N/A
Q1: 2N7002; SOT-23; Digikey 2N7002H6327XTSA2CT-ND
R1: 10k; R_0603_1608Metric; Digikey RMCF0603JT10K0CT-ND
R2: 22R; R_0603_1608Metric; Digikey RMCF0603JT22R0CT-ND
R3: 1M; R_0603_1608Metric; Digikey RMCF0603JT1M00CT-ND

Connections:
/BACKLIGHT_EN: J1.3, J4.3, R1.1
/DC: J1.4, J2.7, J4.4
/LEDA: J2.3, R2.2
/LEDK: J2.2, Q1.3 (D)
/MOSI: J2.10, J3.3, J5.3
/SCK: J2.9, J3.2, J5.2
/VDD: C1.1, C2.1, J1.2, J2.4, J4.2, R2.1
/nCS: J2.8, J3.1, J5.1
/nRESET: J2.11, J3.4, J5.4
GND: C1.2, C2.2, J1.1, J2.1, J2.5, J2.6, J2.12, J4.1, Q1.2 (S), R3.2
unnamed: Q1.1 (G), R1.2, R3.1

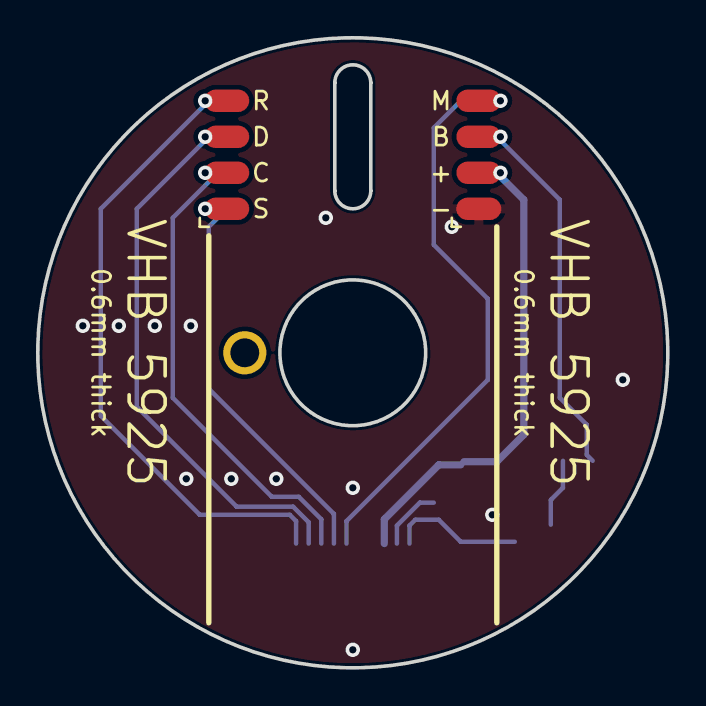
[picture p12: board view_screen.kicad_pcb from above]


Board: 2 copper layers, 35.0 x 35.0 mm, 12 parts (9 on the bottom side), 11 nets.

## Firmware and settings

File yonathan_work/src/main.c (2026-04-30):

#include <stdio.h>

// Raspberry Pi Pico SDK Headers
#include "pico/stdlib.h"
#include "hardware/adc.h"
#include "hardware/dma.h"
#include "hardware/gpio.h"
#include "hardware/irq.h"
#include "hardware/resets.h"
#include "hardware/spi.h"
#include "hardware/timer.h"

// Third-Party Libraries
#include "lvgl.h"

// Project-Specific Local Headers
#include "board_config.h"
#include "as5600.h"
#include "ldr_monitoring.h"
#include "mode_controls.h"
#include "motor_modes.h"
#include "motor_feedback.h"
#include "display.h"
#include "ui/ui.h"

// --- MAIN LOOP ---
int main() {
    stdio_init_all();
    ui_mode_t current_mode = UI_MODE_UNBOUNDED_NO_DETENTS;
    absolute_time_t next_ui_update = make_timeout_time_ms(10);

    if (!as5600_init()) {
        printf("AS5600 init failed\n");
    }

    lcd_init();
    mode_controls_init();

    // LDR controlling LCD backlight
    init_adc_dma();
    init_pwm_static(10000, 5000); 
    init_pwm_irq(); 
    
    // LVGL Setup
    lv_init();
    static lv_color_t buf_1[MY_DISP_HOR_RES * 24];
    static lv_disp_draw_buf_t draw_buf;
    lv_disp_draw_buf_init(&draw_buf, buf_1, NULL, MY_DISP_HOR_RES * 24);

    static lv_disp_drv_t disp_drv;
    lv_disp_drv_init(&disp_drv);
    disp_drv.hor_res = MY_DISP_HOR_RES;
    disp_drv.ver_res = MY_DISP_VER_RES;
    disp_drv.flush_cb = my_disp_flush; 
    disp_drv.draw_buf = &draw_buf;
    lv_disp_drv_register(&disp_drv);

    // Call the external UI function!
    ui_init();
    ui_show_startup_screen("Calibrating...");
    lv_timer_handler();

    if (!motor_feedback_init(current_mode)) {
        printf("Motor feedback disabled\n");
    }

    motor_modes_init(current_mode);

    while (1) {
        motor_feedback_update();

        if (time_reached(next_ui_update)) {
            next_ui_update = make_timeout_time_ms(10);
            lv_timer_handler();
            mode_controls_update();

            if (mode_controls_consume_advance_request()) {
                current_mode = (ui_mode_t)((current_mode + 1) % UI_MODE_COUNT);
                motor_feedback_set_mode(current_mode);
                motor_modes_set_mode(current_mode);
            }

            motor_modes_update(current_mode);
        }
    }

    return 0;
}

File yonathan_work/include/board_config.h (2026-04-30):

#ifndef BOARD_CONFIG_H
#define BOARD_CONFIG_H


#include "pico/stdlib.h"
#include "hardware/spi.h"
#include "hardware/uart.h"

// MOTOR DRIVER (all are pulled down)
#define MOTOR_PHASE_V_LOW_PIN       2
#define MOTOR_PHASE_V_HIGH_PIN      3
#define MOTOR_PHASE_W_LOW_PIN       4
#define MOTOR_PHASE_W_HIGH_PIN      5
#define MOTOR_PHASE_U_LOW_PIN       6
#define MOTOR_PHASE_U_HIGH_PIN      7
#define MOTOR_DIAG_PIN             14

// UART
#define DEBUG_UART         uart0
#define DEBUG_UART_RX_PIN  1
#define DEBUG_UART_TX_PIN  0
#define DEBUG_UART_BAUD    115200

#define SERIAL_UART        uart1
#define SERIAL_UART_RX_PIN 8
#define SERIAL_UART_TX_PIN 9

// STRAIN SENSOR (rate 1  80 samples / second)
#define STRAIN_DO_PIN  10
#define STRAIN_SCK_PIN 11

// LDR PINS 
#define LDR_V_IN 45
#define LDR_ADC_CHAN 5
#define LDR_CLK_DIV 2.5e6

// LCD
#define LCD_SPI_CHAN spi0
#define MY_DISP_HOR_RES 240
#define MY_DISP_VER_RES 240
#define LCD_CMD_PIN 15
#define LCD_BACKLIGHT_PIN 16
#define LCD_BACKLIGHT_PWM_CHAN 0
#define LCD_CS_PIN 17
#define LCD_SCK_PIN 18
#define LCD_DATA_PIN 19
#define LCD_RST_PIN 20
#define BUTTON_PIN 21

// LED_DATA
#define LED_DATA_3V3_PIN  27; 

// AS5600 MAGNETIC ENCODER (I2C)
#define MAG_ENC_I2C_PORT  i2c0
#define MAG_ENC_I2C_SDA   28 
#define MAG_ENC_I2C_SCL   29 

// CONTROL SETTINGS
#define MOTOR_CONTROL_HZ    4000.0f
#define MOTOR_PWM_WRAP      4000

// motor config
// MOTOR CONFIG
#define MOTOR_DEFAULT_POLE_PAIRS    7
#define MOTOR_SUPPLY_VOLTAGE        5.0f
#define MOTOR_VOLTAGE_LIMIT         3.5f
#define MOTOR_ENCODER_FILTER_ALPHA  0.10f
#define MOTOR_VELOCITY_FILTER_ALPHA 0.12f
#define MOTOR_VELOCITY_NOISE_DEADBAND_RAD_S 0.20f

#endif

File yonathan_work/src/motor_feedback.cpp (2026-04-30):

#include "motor_feedback.h"
#include <math.h>
#include <stdint.h>
#include <stdio.h>
#include "hardware/gpio.h"
#include "pico/stdlib.h"
#include "SimpleFOC.h"
#include "as5600.h"
#include "board_config.h"

namespace {

constexpr float kTwoPi = 6.2831853071795864769f;
constexpr float kPi = 3.1415926535897932385f;
constexpr float kDegToRad = 0.017453292519943295f;
constexpr float kRadToDeg = 57.29577951308232f;

struct HapticModeProfile {
    bool uses_active_torque;
    int32_t min_position;       
    int32_t max_position;       
    float position_width_rad;   
    float detent_strength;      
    float endstop_strength;     
    float damping_factor;       
    float snap_point;           
    float snap_point_bias;      
    float dead_zone_rad;        
};

constexpr HapticModeProfile kHapticProfiles[UI_MODE_COUNT] = {
    { false, 1, 0, 0.0f, 0.0f, 0.0f, 0.0f, 0.5f, 0.0f, 0.0f },
    { true, 1, 0, 15.0f * kDegToRad, 1.2f, 0.0f, 0.04f, 0.55f, 0.05f, 0.5f * kDegToRad },
    { true, 0, 10, 20.0f * kDegToRad, 2.8f, 15.0f, 0.06f, 0.55f, 0.10f, 0.8f * kDegToRad },
    { true, 0, 1, 140.0f * kDegToRad, 3.8f, 60.0f, 0.08f, 0.60f, 0.15f, 1.0f * kDegToRad }
};

ui_mode_t current_mode = UI_MODE_UNBOUNDED_NO_DETENTS;
bool initialized = false;
float unwrapped_angle_rad = 0.0f;
float last_wrapped_rad = 0.0f;
float velocity_rad_s = 0.0f;

float haptic_logical_offset_rad = 0.0f;
float haptic_center_rad = 0.0f;
int32_t haptic_current_position = 0;
float haptic_idle_velocity_ewma = 0.0f;
uint32_t last_idle_start_ms = 0;

float wrapAngleDelta(float delta) {
    while (delta > kPi) delta -= kTwoPi;
    while (delta < -kPi) delta += kTwoPi;
    return delta;
}

float clampFloat(float value, float min_value, float max_value) {
    return fminf(fmaxf(value, min_value), max_value);
}

void initializeHapticState(ui_mode_t mode, float unwrapped_angle) {
    haptic_logical_offset_rad = unwrapped_angle;
    haptic_current_position = 0; 
    haptic_center_rad = 0.0f;
    haptic_idle_velocity_ewma = 0.0f;
    last_idle_start_ms = 0;
}

class AS5600Sensor : public Sensor {
public:
    bool begin() {
        bool ok = as5600_read_raw(&last_raw_);
        if (ok) {
            filtered_angle_ = ((float)(last_raw_ & 0x0FFF) * kTwoPi) / 4096.0f;
            last_update_us_ = time_us_64();
            Sensor::init();
        }
        return ok;
    }
protected:
    float getSensorAngle() override {
        uint16_t raw;
        if (as5600_read_raw(&raw)) {
            float rad = ((float)(raw & 0x0FFF) * kTwoPi) / 4096.0f;
            float delta = wrapAngleDelta(rad - filtered_angle_);
            filtered_angle_ += MOTOR_ENCODER_FILTER_ALPHA * delta;
            uint64_t now = time_us_64();
            float dt = (float)(now - last_update_us_) * 1e-6f;
            if (dt > 0.0001f) {
                float inst_vel = (MOTOR_ENCODER_FILTER_ALPHA * delta) / dt;
                filtered_velocity_ += MOTOR_VELOCITY_FILTER_ALPHA * (inst_vel - filtered_velocity_);
                last_update_us_ = now;
            }
        }
        return filtered_angle_;
    }
    uint16_t last_raw_ = 0;
    float filtered_angle_ = 0.0f;
    float filtered_velocity_ = 0.0f;
    uint64_t last_update_us_ = 0;
};

AS5600Sensor sensor;
BLDCMotor motor(7); // Explicit pole pairs
BLDCDriver6PWM driver(MOTOR_PHASE_U_HIGH_PIN, MOTOR_PHASE_U_LOW_PIN, 
                      MOTOR_PHASE_V_HIGH_PIN, MOTOR_PHASE_V_LOW_PIN, 
                      MOTOR_PHASE_W_HIGH_PIN, MOTOR_PHASE_W_LOW_PIN);

float calculateSmartKnobVoltage(float logical_angle, float velocity, const HapticModeProfile& profile) {
    if (!profile.uses_active_torque || profile.position_width_rad <= 0.0f) return 0.0f;

    bool has_bounds = profile.min_position <= profile.max_position;
    float angle_to_center = logical_angle - haptic_center_rad;

    // --- State Transitions ---
    float snap_rad = profile.position_width_rad * profile.snap_point;
    float bias_rad = profile.position_width_rad * profile.snap_point_bias;
    float snap_inc = snap_rad + (haptic_current_position >= 0 ? -bias_rad : bias_rad);
    float snap_dec = -snap_rad + (haptic_current_position <= 0 ? bias_rad : -bias_rad);

    if (angle_to_center > snap_inc && (!has_bounds || haptic_current_position < profile.max_position)) {
        haptic_center_rad += profile.position_width_rad;
        angle_to_center -= profile.position_width_rad;
        haptic_current_position++;
    } else if (angle_to_center < snap_dec && (!has_bounds || haptic_current_position > profile.min_position)) {
        haptic_center_rad -= profile.position_width_rad;
        angle_to_center += profile.position_width_rad;
        haptic_current_position--;
    }

    // --- Absolute Center Correction (Scott's Logic) ---
    // Clamping ensures haptic_center_rad stays exactly on the logical step
    if (has_bounds) {
        haptic_center_rad = clampFloat(haptic_center_rad, 
                                       (float)profile.min_position * profile.position_width_rad, 
                                       (float)profile.max_position * profile.position_width_rad);
    }

    // --- End-Stop Detection ---
    bool out_of_bounds = has_bounds && (
        (angle_to_center > 0.0f && haptic_current_position == profile.max_position) ||
        (angle_to_center < 0.0f && haptic_current_position == profile.min_position)
    );

    // --- Idle Drift Lock ---
    haptic_idle_velocity_ewma = velocity * 0.001f + haptic_idle_velocity_ewma * 0.999f;
    if (fabsf(haptic_idle_velocity_ewma) > 0.05f) {
        last_idle_start_ms = 0;
    } else if (last_idle_start_ms == 0) {
        last_idle_start_ms = to_ms_since_boot(get_absolute_time());
    }

    // Only "relax" if in-bounds. If out of bounds, wall stays rigid
    uint32_t now = to_ms_since_boot(get_absolute_time());
    if (!out_of_bounds && last_idle_start_ms > 0 && (now - last_idle_start_ms) > 500 &&
        fabsf(logical_angle - haptic_center_rad) < (5.0f * kDegToRad)) {
        haptic_center_rad = logical_angle * 0.0005f + haptic_center_rad * 0.9995f;
    }

    // --- Force Calculation ---
    const float strength = out_of_bounds ? profile.endstop_strength : profile.detent_strength;
    const float dead_zone = out_of_bounds ? 0.0f : clampFloat(angle_to_center, -profile.dead_zone_rad, profile.dead_zone_rad);
    
    float p_force = strength * (-(angle_to_center - dead_zone));
    float d_force = -(strength * profile.damping_factor * velocity);

    if (out_of_bounds) {
        bool moving_deeper = (angle_to_center * velocity) > 0;
        if (!moving_deeper) {
            // SNAP-BACK BOOST: If user lets go, double the spring force and kill the brake
            p_force *= 1.5f; 
            d_force = 0.0f; 
        } else {
            d_force *= 4.0f; // Heavy resistance moving in
        }
    }

    return clampFloat(p_force + d_force, -MOTOR_VOLTAGE_LIMIT, MOTOR_VOLTAGE_LIMIT);
}

} // namespace
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

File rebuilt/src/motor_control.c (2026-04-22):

#include "motor_control.h"

// Interrupt handler for motor fault detection
void motor_fault(uint gpio, uint32_t events) {
    // Clear the interrupt by acknowledging it
    gpio_acknowledge_irq(MOTOR_DIAG_PIN, events);
    printf("Motor fault detected\n");

    // Disable the motor driver to reset the motor
    disable_motor();
    sleep_ms(1000); // Delay in case fault not cleared immediately
    enable_motor(); // Re-enable
}

// Initialize the MOTOR_VIO pin (high by default, low to disable motor driver)
void init_motor_control(void) {
    // Initialize the GPIO pins
    gpio_init(MOTOR_VIO_PIN);
    gpio_init(MOTOR_DIAG_PIN);
    
    // Set IO
    gpio_set_dir(MOTOR_VIO_PIN, GPIO_OUT);
    gpio_set_dir(MOTOR_DIAG_PIN, GPIO_IN);
    
    // Set high by default (motor enabled)
    gpio_put(MOTOR_VIO_PIN, 1);
    
    // Enable pull-down (assumes fault signal pulls high)
    gpio_pull_down(MOTOR_DIAG_PIN);
    
    // Set interrupt to trigger on high level with callback
    gpio_set_irq_enabled_with_callback(MOTOR_DIAG_PIN, GPIO_IRQ_LEVEL_HIGH, true, &motor_fault);
}

// Enable the motor driver (set VIO high)
void enable_motor(void) {
    gpio_put(MOTOR_VIO_PIN, 1);
}

// Disable the motor driver (set VIO low)
void disable_motor(void) {
    gpio_put(MOTOR_VIO_PIN, 0);
}

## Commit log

2026-03-04 init kicad files
    [BM28B0.6-24DSBreakout.kicad_pcb, BM28B0.6-24DSBreakout.sch, LevelShifterBreakout.kicad_pcb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]
2026-03-09 sunday work
    [view_base.kicad_pcb, view_base.kicad_sch]
2026-03-09 Adding pin assignment spreadsheet
    [ProjectPinAssignments.xlsx]
2026-03-28 filled out excel with pin mappings using gemini (pls validate if possible)
    [ProjectPinAssignments.xlsx]
2026-03-28 changed GPIO for UL/UH to accomodate debugger TX and RX
    [ProjectPinAssignments.xlsx]
2026-03-28 initial layout
    [view_base.kicad_pcb]
2026-03-28 more layout and simplification
    [view_base.kicad_pcb, view_base.kicad_sch]
2026-03-28 added RP 2350 pin table
    [ProjectPinAssignments.xlsx]
2026-03-29 Reassigned pins in excel sheet
    [ProjectPinAssignments.xlsx]
2026-03-30 more layout
    [view_base.kicad_pcb, view_base.kicad_sch]
2026-03-31 Firmware/Must calibrate everything before testing
    [configuration.h, partitions-4MB-fat.csv]
2026-03-31 I added the programming but there are two .ini files. Please advise to change these and the current code runs on my user. You need to change this or use my computer to flash the smartknob
    [configuration.h]
2026-03-31 worked on some routing and edited the ground plane, feel free to revert just wanted to mess with it
    [view_base.kicad_pcb]
2026-03-31 got rid of some ground traces in favor of using plane
    [view_base.kicad_pcb]
2026-04-01 finished layout
    [view_base.kicad_pcb, view_base.kicad_sch]
2026-04-02 redid routing and schematic to match GPIO pins from excel
    [view_base.kicad_pcb, view_base.kicad_sch]
2026-04-03 consult TA about layout
    [view_base.kicad_pcb]
2026-04-03 Changed TMC6300 footprint to make vias into thermal reliefs to get rid of drc, added in project title and purdue P
    [view_base.kicad_pcb]
2026-04-16 Creating folder for build from ground 0
2026-04-16 added LDR pin in excel
    [ProjectPinAssignments.xlsx]
2026-04-16 fixed things for ldr pin
    [ProjectPinAssignments.xlsx]
2026-04-17 got rid of unneccessary files
    [configuration.h, partitions-4MB-fat.csv]
2026-04-17 test file. need to construct wheatstone bridge
    debugging and calibration required. This code reads the analog voltage value on the assigned pin and supposed hx711 high and low output. We need to calibrate the amplifier by "taring" to the load cel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
2026-04-18 finished making HX711 code that works with wheatstone bridge (1k resistors with 1k pot)
2026-04-18 Adding support to change states with button on the Proton
2026-04-18 disregard earlier commit. Remembered I already made the button change states inside of the state machine file
2026-04-18 updated encoder pins since it is now i2c
2026-04-18 adding ported library for encoder
2026-04-18 supporting functions for as5600 mag encoder
2026-04-19 Adding support for simple FOC to control the motor and updated the state machine system to support tracking of the position more cleanly.
2026-04-19 It's absolutely tweaking out with alleged problems but the thing compiles with platformio
    [as5600.c, board_config.h, ldr_monitoring.c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]
2026-04-19 started with motor control stuff
    [ProjectPinAssignments.xlsx]
2026-04-22 Adding motor control
2026-04-22 added motor folder
2026-04-22 added motor folder and most recent code
2026-04-22 added in hx711 modules to motor folder
2026-04-22 got rid of rebuilt_playground and renamed rebuilt as old since motor is our main working folder
2026-04-22 cleaned up main.c, added display.h and display.c in motor folder (untested on actual hardware)
2026-04-22 added in some changes to some .h and .c files with c++ sections to get rid of warnings/errors
    [Arduino.h]
2026-04-22 moved pin assignment excel into electronics folder
    [ProjectPinAssignments.xlsx]
2026-04-22 Added Links to proton and pin assignment excel
2026-04-29 Added changes to fix mode skipping and angle drift following calibration
    [main.c]

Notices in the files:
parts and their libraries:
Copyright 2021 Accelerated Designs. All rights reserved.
